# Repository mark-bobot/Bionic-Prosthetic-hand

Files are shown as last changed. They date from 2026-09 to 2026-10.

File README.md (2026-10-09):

# Bionic Prosthetic Hand

**One-wearer preparation:** [selected build and open acceptance gates](release/production/README.md). The latest files form an engineering bench kit; the device is not production-ready or approved for fitted use.

A three-servo adaptation of the e-NABLE Phoenix Hand v3, using a DFRobot SEN0240 dry-electrode EMG sensor and an Arduino Nano.

One servo drives the thumb, one drives the index and middle fingers, and one drives the ring and little fingers. When explicitly enabled for fixture commissioning, the controller commands closure on contraction and opening on relaxation; outputs ship disabled and mechanical operation remains untested. The original palm and finger shapes are retained.

**Before human testing:** [start with the unpowered printed-hand checks](docs/PRE-HUMAN-TEST.md). Current wiring and software preparation are included; physical verification and professional fitting remain outstanding.

## Latest routing variant — tendon drums underneath

The [bottom-drive candidate](cad/bottom_drive/README.md) inverts the three motors inside the enclosure and lowers the cord exits by 29.9–42.1 mm. The arm adapter and original hand are retained. A bolted upper motor carrier replaces reliance on hanging ties. Ideal pulling force is unchanged; reduced friction remains a bench-test question.

## Lower enclosure and rigid arm adapter

The [lower box and arm adapter](cad/cuff_box_compact/README.md) reduces enclosure height by 23.2%, retains one motor per pair of fingers, and adds a bolted arm carrier and palm receiver. It requires the shorter replacement-servo candidate; actual component fit and fitted use remain unverified.

## Earlier alternative — removable box above the original cuff

The [separate cuff-box design](cad/cuff_box/README.md) keeps the Phoenix hand and original gauntlet geometry unchanged. Three servos and upright Nano/EMG boards fit inside a strap-on enclosure; the battery stays external. This is a separate, minimally invasive packaging option. Its cuff view is an envelope, and wrist stabilisation and wearer fit remain unresolved.

## Historical alternative — components inside the forearm

[Historical 0.4.3 forearm guide](cad/forearm/README.md). A split, curved arm shell houses the motors, battery, electronics and tendon mechanism; the separate top box is removed. The original v3 placemat confirms the finger order; the previously inverted fingertips are now rolled correctly, with their pads toward the palm. The thumb now uses the original palm hinge, and the added side bracket is removed. The maximum forearm section is about **102 × 102 mm**. This version retains the low-profile replacement-servo candidate and revised power requirements.

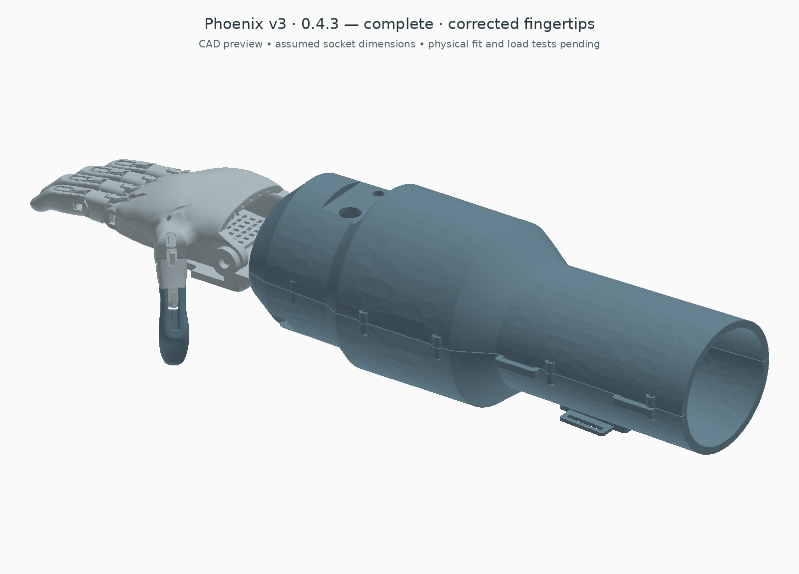
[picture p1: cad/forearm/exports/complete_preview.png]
Forearm-integrated design


[Hand layout close-up](cad/forearm/exports/hand_layout_preview.png) · [See the internal arrangement](cad/forearm/exports/open_preview.png) · [Electronics underneath](cad/forearm/exports/electronics_preview.png) · [Complete STEP](cad/forearm/exports/complete_forearm.step)

**Remaining limits:** the model assumes 160 mm from residual-limb end to wrist. Corrected fingertip poses pass the sampled collision checks, but recipient dimensions, continuous joint motion, tendon load and real hardware fit still need validation before this becomes a functional or fitted hand. The assembly reserves empty limb space rather than filling it with components.

## Adjustable hand sizing

The [sizing study](cad/sizing/README.md) adds an editable Phoenix scale percentage and independent arm-clearance dimensions. It preserves the original hand proportions and corrected fingertip orientation while keeping hardware full size. The illustrated 120% hand is a comparison, not a selected wearer size. The [new receiver and matching assembly](cad/sizing/ADAPTER.md) connect that hand to the housing with local screw-head clearances in the lower shell. An individually fitted socket remains outstanding.

## Build files

- [Arduino code and setup](firmware/README.md)
- [Wiring diagram](docs/WIRING.md)
- [Editable CAD, STEP and printable STL files](cad/README.md)
- [Right forearm attachment and movable EMG holder](cad/arm_interface/README.md) — unfitted concept
- [Bill of materials and cost allowances](BOM.md)
- [Candidate force and travel calculation](cad/slim/README.md#force-screen) · [Earlier generic-servo calculation](calculations/README.md)
- [Measuring tendon force](TENDON-TEST.md)
- [Checks performed](VALIDATION.md)
- [What remains](TODO.md)

## Earlier layouts

[The 0.3 smaller top-box candidate](cad/slim/README.md) and [0.2.1 external housing](cad/bionic/README.md) remain as history and sources for reused parts. Their assembly previews predate the finger assignment and thumb placement corrections. Use the 0.4.3 guide for current part selection; do not combine old shells or receivers with it.

[Simple averaging code](firmware/README.md) · [Current mechanical hardware](cad/forearm/README.md#selected-parts-and-hardware)

## Status

This is a newly reconstructed bench-prototype design. The Nano sketch compiles and the software control tests pass. The newly generated add-on parts pass solid/mesh checks; some original Phoenix STEP-to-STL conversions fail watertightness checks, so use the official source STLs. The hardware has not been assembled or tested: motor fit, tendon load, grip performance, electrical noise and thermal performance remain unverified.

The servos owned for this project are generic units advertised as 25 kg·cm with 180° travel. DS3225 dimensions and 5 V electrical specifications were historical references. The selected bottom-drive candidate instead uses FT5425BL references and its own power specification; neither identifies the owned motors. The initial code uses a small test movement; calibrate endpoints before expecting full finger closure.

The source project description mentions improved electrode contact, averaging sensor readings, tendon actuation and sharing a servo between two fingers. The files here implement a new version of that idea; they are not recovered original firmware or CAD, and do not establish earlier test results.

## Original design

Phoenix Hand v3 is credited by [e-NABLE](https://hub.e-nable.org/p/devices?p=e-NABLE+Phoenix+Hand+v3) to Jason Bryant, John Diamond, Scott Darrow, Andreas Bastian, Team Unlimbited, e-NABLE France and Jeremy Simon. It derives from Phoenix Hand v2 and Unlimbited Phoenix Hand, with labelled pins among the v3 changes.

The [original Thingiverse design](https://www.thingiverse.com/thing:4056253) is CC BY 4.0. The official STEP file is included unchanged; new carrier, spool, guide and equaliser parts are separate. The mechanical change is rerouting wrist-driven tendons to external servo actuation. No endorsement by the original designers is implied.

## Licences

Documentation and mechanical CAD: **CC BY 4.0**. Original firmware: **MIT**. Included OYMotion filter files: **BSD-2-Clause**, with their notices retained. Arduino's Servo library is an external **LGPL-2.1-or-later** dependency. See [LICENSE.md](LICENSE.md).

This is an educational bench prototype, not a validated fitted prosthesis.

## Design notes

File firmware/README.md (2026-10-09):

# Firmware

**10 October 2026: servo outputs are disabled by default.** `SERVO_OUTPUTS_ENABLED = false` is a commissioning lock, not a human-use approval mechanism. Read [pre-human-test preparation](../docs/PRE-HUMAN-TEST.md) and [current wiring](../docs/WIRING.md). No person connected during initial commissioning.

Open `ProstheticHand/ProstheticHand.ino` in Arduino IDE. Select **Arduino Nano / ATmega328P** and install Arduino's **Servo** library. The OYMotion EMG filter is included beside the sketch, so there is no separate EMG library to install. Some older Nano bootloaders require the IDE's Old Bootloader option.

## The simple averaging step

Open `ProstheticHand/ProstheticHand.ino`; keep its helper files in the same folder. The sketch reads A0, filters the signal, averages its activity and moves the three groups together. The averaging helper in `HandControl.h` is:

```cpp
sum -= history[index];                 // oldest sample out
history[index] = uint32_t(value * value);
sum += history[index];                 // newest sample in
index = (index + 1) % AVERAGE_SAMPLES;
level = sum / AVERAGE_SAMPLES;          // mean of 32 consecutive activity samples
```

`value` is the filtered EMG after the arithmetic-range clamp. Squaring before averaging measures activity; averaging the raw signal alone would drift around its DC bias and can hide contraction. `AVERAGE_SAMPLES = 32` gives a 32 ms window at the 1 kHz sampling rate. Change the three `OPEN_US`/`CLOSE_US` pairs only after calibrating the real mechanisms. Calibration, arming and the hold timeout remain in the helper so the main sketch stays short.

## What it does

The sensor connects to A0. The code samples at nominally 1 kHz, uses OYMotion's 50 Hz notch/high-pass/low-pass filters, squares the filtered signal using 32-bit arithmetic, and averages 32 consecutive samples. This follows the processing direction of [DFRobot's SEN0240 example](https://wiki.dfrobot.com/sen0240/docs/20737), with averaging and servo control added.

On reset, keep the muscle relaxed for five seconds. The first second lets the filter settle; the remaining four estimate the largest resting activity. The closing threshold is three times that resting peak plus 25, with a minimum of 100. These are initial tuning choices, not universal physiological thresholds. Activity must exceed the threshold for 80 ms before closing. It must fall below half the threshold to reopen. A grip command times out after three seconds and requires relaxation before another grip.

There is one EMG channel. It commands all three groups together; it cannot independently select a finger or grip pattern.

| Pin | Connection |
| --- | --- |
| A0 | SEN0240 A; add 1 MΩ to GND |
| D2 | Normally-open momentary hold-to-enable switch to GND, internal pull-up |
| D9 | Thumb servo signal |
| D10 | Index/middle servo signal |
| D11 | Ring/little servo signal |
| 5V | Clean regulated 5 V logic supply; not servo power |
| GND | Shared signal reference, with motor returns routed separately |

## First run

1. Program with electrodes removed, servo supply off and external logic supply disconnected from the Nano. Unplug USB before body-connected battery testing.
2. On the fixture, provide a resting test input and leave the enable switch open. Wait five seconds. The LED lights when calibration completes; rapid blinking indicates a latched fault. Calibration alone does not enable outputs.
3. For the first servo check, remove horns/tendons and confirm motor model and supply. Deliberately set `SERVO_OUTPUTS_ENABLED = true` and recompile for the fixture test. Release the switch **after calibration** for at least 50 ms, then hold it to enable. A switch held across startup/reset remains inhibited. Simulate rest, activity and rest; never use a person as the initial test input. Reattaching commands `OPEN_US`; it does not know the motor's physical position.
4. `OPEN_US = 1100` and `CLOSE_US = 1300` are deliberately small test movements, not full closure. Determine unloaded endpoints one servo at a time, then attach loose tendons and increase travel gradually. Never use nominal angle alone to establish the real range. Change the arrays separately if a servo must turn in the other direction.
5. Set `PLOT = true` only for diagnostic logging using an appropriately isolated arrangement, or with electrodes disconnected. Output columns are activity, threshold and close command. Do not connect a mains-connected computer while electrodes are worn.

A signal that stays above threshold prevents a new grip after rearming or timeout. Motor noise can trigger false contractions: test with motor power off and on before loaded tendons. Wearer calibration is a separate professionally reviewed stage. A lost or noisy electrode can still look plausible.

## Limits

The software does not measure tendon tension, grip force, temperature or actual finger position. The ADC rail check can catch some broken connections but cannot reliably detect electrode loss: a disconnected/noisy electrode can still look valid. The arm switch detaches servo signals; servo gearing may remain resistant to movement. It is not an emergency mechanical release. The main power switch and accessible tendon release remain necessary for bench work.

A sampling delay of at least 2 ms latches a fault. The loop schedule has not been measured on hardware; the compiled firmware is not a real-time validation result.

## Reproduce checks

```
arduino-cli core install arduino:avr
arduino-cli lib install Servo
arduino-cli compile --fqbn arduino:avr:nano:cpu=atmega328 firmware/ProstheticHand
c++ -std=c++11 tests/control_test.cpp -o /tmp/control_test
/tmp/control_test
```

Original control code: MIT. Included `EMGFilters.cpp` and `.h`: OYMotion BSD-2-Clause, with notices retained. Source linked by DFRobot: https://github.com/YeezB/EMG_Filter at commit `867fa1d30244b22f28a68787adfd5648066c4736`. Arduino Servo is an external LGPL-2.1-or-later dependency; no firmware binary is distributed here.

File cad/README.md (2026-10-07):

# Mechanical build

**Current direction:** [0.4.3 forearm-integrated Phoenix](forearm/README.md). Electronics and motors are inside the split arm shell. The former top-box and custom-hand studies are superseded.

The Phoenix v3 palm, fingers and joints are kept unchanged. The new parts form an internal forearm equipment bay, with a corrected finger assignment and thumb restored to the native palm hinge. Full source-joint flexion remains unaccepted. Tendons are rerouted from the original wrist-powered actuation to the servos. This is the current reconstruction; it is not evidence that the original project used this exact arrangement.

## Earlier smaller-part option

[Low-profile replacement-parts candidate](slim/README.md) reduces the housing to 50 mm high. Its complete assembly is `slim/exports/complete_slim_candidate.step`. It requires different servos and power wiring; do not mix the old electrical BOM with this candidate.

## Historical build selection

The historical 0.2.1 selection is recorded in [BUILD.md](../BUILD.md). It used the compact 60 mm housing, single-groove spools, Phoenix v3 source hand and external tendon cassette; its STEP is `bionic/exports/complete_right_bionic.step`. Use [the forearm guide](forearm/README.md) for current files and acceptance gates.

[Revision B](INTEGRATION.md) and the motor-only files below are historical designs. Their base, lid and double-groove spool must not be substituted into the current package.

## Original motor-only files

| File in `exports/` | Quantity | Purpose |
| --- | ---: | --- |
| `servo_carrier.stl` | 1 | Three standard-size servo pockets on a strap-mounted base |
| `two_groove_spool.stl` | 3 | 12 mm groove-floor radius drum; one per servo |
| `pair_equaliser.stl` | 2 | A small floating bar that divides one tendon pull between two fingers |
| `tendon_fairlead.stl` | 3 | Two-bore tie-on guide; PTFE tubing separates tendon from printed plastic |

STEP versions are included for editing. `carrier_assembly.step` includes rectangular reference servo envelopes; those are not printable motor parts. `build.py` is the parametric source, tested with CadQuery 2.8.0. Millimetres throughout. Run `python cad/build.py` to regenerate.

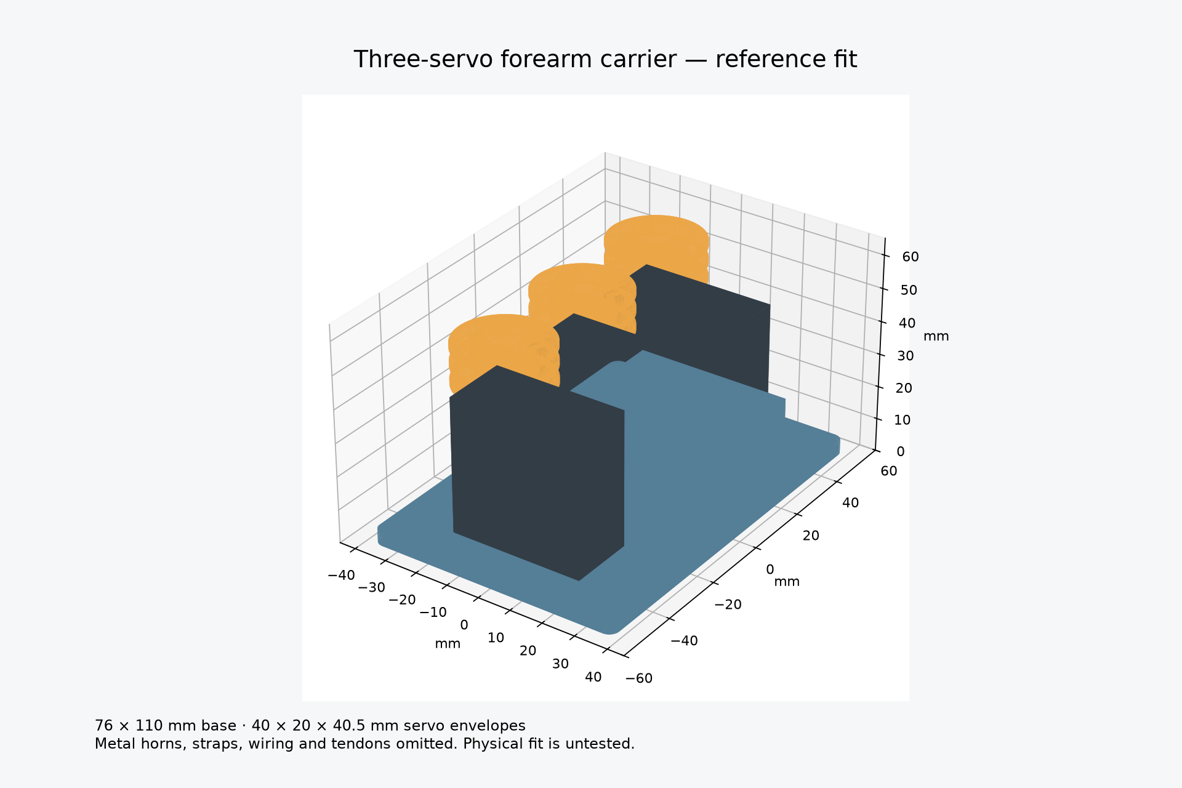
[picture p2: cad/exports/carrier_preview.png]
Carrier


## Carrier and servo retention

The base is 76 × 110 × 4 mm. Each pocket accepts a 40 × 20 mm reference body with 0.5 mm clearance per side. Retaining walls rise 11 mm above the base. There are cable exits and slots for a 4.8 mm tie around the rear of each motor, clear of the assumed output shaft position. Four outer slots take two 25 mm straps; a foam layer belongs between the plate and its support.

This is a test-fit fixture. The reference body dimensions are from DS3225 data; ear shape, lead exit, shaft offset and horn height are not established for the owned servos. The drawing uses a 10 mm shaft offset from the body centre and 3 mm horn clearance as layout assumptions. Check these before printing the full carrier. Servo ears must remain above the short walls and ties must clear the rotating horns. If the body is larger, edit `BODY_L`, `BODY_W` and clearance rather than forcing it into a pocket.

Use the carrier on a bench fixture first. Its width is 110 mm and its nominal assembled height is about 60 mm; this is not a compact palm enclosure or a fitted medical cuff. Final forearm attachment needs actual dimensions and a comfortable load-spreading cuff. It has no direct screw-hole attachment to a Phoenix part, so no Phoenix mounting-hole alignment is claimed.

## Horns and spools

Bolt each printed spool to a metal horn that fits the actual servo spline. Do not try to print a replacement spline. The spool has two 2.3 mm-wide mounting slots centred 8 mm either side of its axis and 6 mm central screwdriver access. Match a horn whose holes fit those slots; otherwise edit the slot positions. Reuse the correct manufacturer horn-retaining screw. Two M2 bolts and nuts per spool are a starting attachment specification; verify bolt length and clearance against the selected horn.

Each groove is 3.75 mm wide. Feed and knot the tendon through its radial anchor hole. Keep one layer of winding: effective radius is the 12 mm groove floor plus half the line diameter. For 0.6 mm line it is approximately 12.3 mm; use that in the torque/travel calculation. Verify the knot clears neighbouring parts and cannot pull through.

## Finger grouping

- D9: thumb; a single line from spool to thumb tendon.
- D10: index and middle; a line from one spool groove to the centre of an equaliser, with the finger tendons tied to its two outer holes.
- D11: ring and little; the same equaliser arrangement.

The unused second spool groove is a spare. Using an equaliser avoids forcing both paired fingers through identical displacement. The bar has 20 mm between outer holes and can accommodate some difference by tilting. Leave room for that motion and keep it away from the other lines. It is not unlimited compensation: if it flips or reaches a stop, stop and adjust the routing. The spool moves approximately the average of the two finger tendon displacements, and its input load is their sum in the nearly parallel arrangement. Measure the real coupling rather than assuming the direct two-groove model in the earlier sizing note.

Retain Phoenix return bands and joints. Disconnect the flexor lines from the original wrist-powered tensioner and route five finger tendons to these three groups. The carrier does not require cutting the original palm. Use the guide blocks at the carrier exit, with 2 mm OD / 1 mm ID PTFE liners and generous bends. Tie the guides to a fixture or cuff; do not leave them unsupported. No exact guide-to-palm path is claimed without hand scale and wrist geometry. Wrist motion can change tendon length, so keep the wrist at a fixed position for the first bench test.

## Printing and inspection

Start with PETG, 0.2 mm layers, four perimeters and approximately 40% infill as trial settings. Print carrier base down, spools axis vertical and equalisers flat. Horizontal cable/anchor bores may need careful clearing; inspect every guide for sharp edges. Print one spool and a pocket test before committing to the full set. These settings are not strength validation.

All four generated parts pass single-solid validity and watertight STL checks. The servo-envelope check finds no volume overlap with the carrier. These checks do not verify actual servo fit, tie retention, layer strength, horn screws, wear or load capacity.

## Original Phoenix file

`upstream/phoenix_v3.step` is the unchanged STEP download linked by the e-NABLE Phoenix v3 catalogue. It imports as 32 solids. SHA-256: `3d7086af7fd8a3b8f33ca87d8af6b10bdc7fc9038eb923bf920633acd7227620`.

Source: https://drive.google.com/file/d/1qt4fIh77aN9F0LTXMMZCiVgzgbxBcUQ3/view
Catalogue and attribution: https://hub.e-nable.org/p/devices?p=e-NABLE+Phoenix+Hand+v3

Phoenix v3 by Jason Bryant, John Diamond, Scott Darrow, Andreas Bastian, Team Unlimbited, e-NABLE France and Jeremy Simon; based on Phoenix v2 and Unlimbited Phoenix. Upstream geometry is CC BY 4.0. New mechanical parts and their parametric CAD source are also CC BY 4.0. No endorsement is implied. Use the official assembly and sizing instructions for the original hand; do not infer recipient fit from this STEP file's scale.

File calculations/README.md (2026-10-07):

# Historical generic-servo force and travel calculation

For the current FT5425BL candidate, see [candidate ratings](../cad/slim/README.md#force-screen). To enter real measurements, use the [actuator-end pull checker](MEASURED-PULL.md). The generic 5 V estimates below are retained as history.

Generated by `python3 calculations/tendon_forces.py`. These are screening calculations, not a measurement of the Phoenix hand.

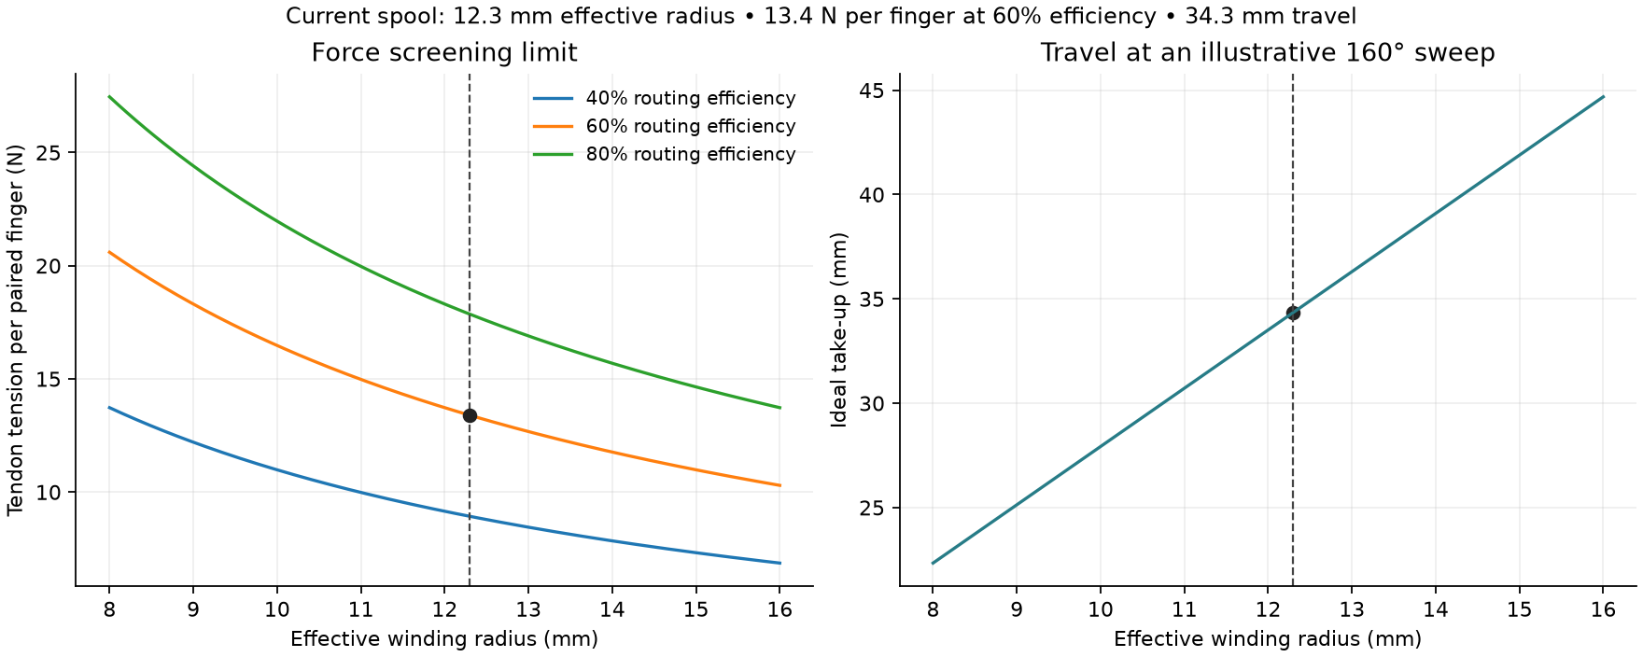
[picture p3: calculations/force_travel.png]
Force and travel trade-off


Optional plot: run `python calculations/plot_forces.py` with matplotlib installed.

## Inputs and equations

Reference stall torque at 5 V: 21 kgf·cm. Assumed working fraction: 40%; torque allowance: 0.824 N·m. Apply a separate 1.5 load margin. Neither allowance is a manufacturer continuous rating.

The new 6.75 mm-high single-groove spool retains its 12 mm groove-floor radius. With 0.6 mm line the effective radius is 12.3 mm. One line pulls a floating equaliser for each pair; one line pulls the thumb. Equal-arm, parallel-line geometry is assumed.

`required torque = margin × radius × (T1 + T2) / routing efficiency`
`equal finger tension limit = efficiency × working torque / (2 × margin × radius)`
`take-up = radius × angular travel in radians`

## Available finger-side tendon tension

| Routing efficiency | Paired fingers, each (N) | Single thumb (N) | Illustrative fingertip force per paired finger (N) |
| --- | ---: | ---: | ---: |
| 40% | 8.93 | 17.86 | 0.49 |
| 60% | 13.39 | 26.79 | 0.94 |
| 80% | 17.86 | 35.72 | 1.39 |

The fingertip column uses `(tendon tension − 4 N) × 5 mm / 50 mm`: an assumed equivalent return/friction tension, tendon moment arm and contact lever. These are not dimensions extracted from Phoenix CAD. A multi-joint finger needs pose-dependent tendon moment arms and contact geometry. Tendon tension is not grip force. The thumb column is tendon tension only.

## Torque required by an assumed load, 60% routing efficiency

| Finger-side tendon pull per finger (N) | Design torque (N·m) | Design torque (kgf·cm) | Within assumed allowance? |
| --- | ---: | ---: | --- |
| 5 | 0.307 | 3.14 | Yes |
| 10 | 0.615 | 6.27 | Yes |
| 15 | 0.922 | 9.41 | No |
| 20 | 1.230 | 12.54 | No |

Required pulls include return bands, finger-joint friction and desired contact load, but exclude routing friction already represented by efficiency. For unequal loads use their sum; a jammed finger can invalidate the equal-load assumption.

## Travel

| Usable sweep | Ideal line take-up |
| --- | ---: |
| 18° | 3.86 mm |
| 120° | 25.76 mm |
| 160° | 34.35 mm |
| 180° | 38.64 mm |

160° is an illustrative calibrated range, not the firmware command. The small initial firmware sweep is about 18° on the reference servo. For an ideal equaliser, input travel is the average of output travels; its tilt and mechanical stops must accommodate their difference. A 20/30 mm finger-travel pair needs 25 mm centre travel and 10 mm differential travel. An equaliser hitting a stop no longer shares force as assumed.

If measuring with a force gauge at the servo end through the complete routing, the total input-force screening limit is **44.65 N**. Compare `1.5 × measured input force × 0.0123 m` against 0.824 N·m; do not divide by routing efficiency again.

## What the numbers establish

At 60% routing efficiency the model supports about 13.4 N per paired finger. Two fingers requiring 10 N each are within the assumed allowance; two requiring 15 N each are outside it. Actual required closure force is unknown. Measure maximum force and travel with return bands installed, first unloaded and then on a bench contact fixture. Record breakaway peaks and the highest winding radius. Do not tighten live tendons on a wearer to establish these values.

Reducing spool height preserves the force/travel calculation; reducing radius would raise force but reduce travel. The new spool still requires real horn, screw-head, tendon-anchor and printed-strength checks. These force estimates do not validate the motor restraints, wrist cradle or socket.

[Manufacturer reference datasheet](https://dsservo.com/d_file/DS3225%20datasheet.pdf), checked 5 October 2026. The owned generic servo is not identified by this reference.

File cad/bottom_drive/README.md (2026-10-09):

# Bottom tendon drive

This variant turns the **three motors and their drums upside down inside the enclosure**. The arm adapter, palm receiver and original Phoenix hand stay in the same position. The cords leave near the bottom of the box, outside the arm shell; they do not run against the residual limb.

The change is worth testing because it lowers the tendon exits and the lever acting on the box mount. It does **not** increase the motor's torque or change the drum's mechanical advantage.

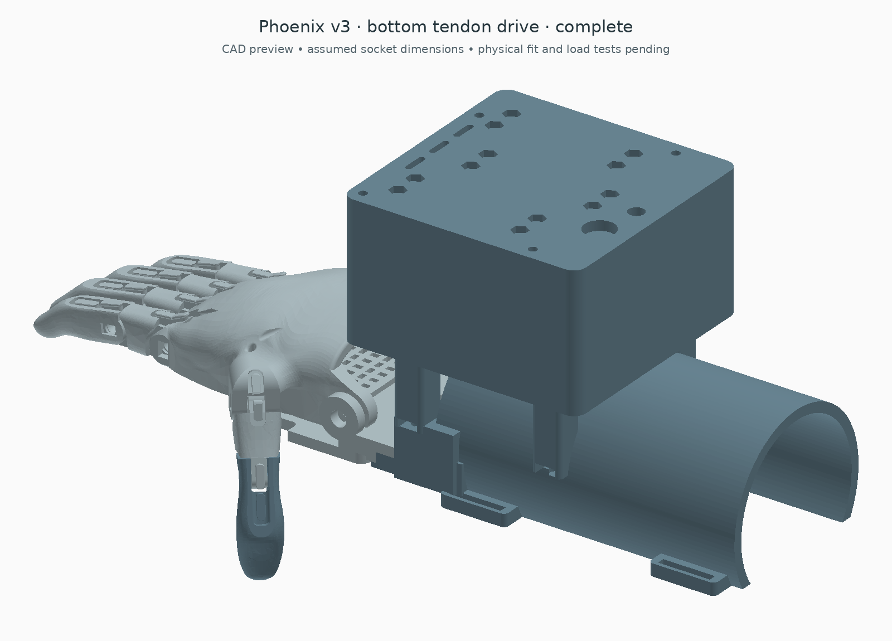
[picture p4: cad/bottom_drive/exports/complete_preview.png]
Complete reference


[Drums viewed from below](exports/drive_detail_preview.png) · [Open box](exports/open_preview.png) · [Complete STEP](exports/complete.step) · [Geometry checks](exports/checks.json) · [Before/after schematic](exports/routing_comparison.png) · [Calculated comparison](exports/routing_comparison.json)

## What changes

- Motors point down, with their drums protected inside the case.
- A 4 mm upper cover carries the motor locating seats and mounting pillars. Four M3 bolts per motor pass through the servo ears into captive nuts in the cover. Ties are not the primary hanging restraint.
- The drawing-based ear-hole pattern is 49.5 × 10 mm. Actual screws, horn and ear fit still require a measured servo.
- The five tendon exits move from 42.4 / 48.5 mm above the box floor to 12.5 / 6.4 mm. This lowers individual exits by 29.9–42.1 mm.
- The box remains 94 × 96 × 54.9 mm. External fastener projections and cable bends are not included in those body dimensions.
- The lower arm adapter and its four M4 mounting points stay unchanged.

The load path is drum → servo case → ear bolts → structural cover → cover screws → case → M4 arm mounts. The cover and its fasteners therefore need load testing as structural parts.

The mechanism still has **three servos**: thumb; index/middle; ring/little. Each paired motor winds two independent cords in separate grooves. It gives fixed coupled travel, not an adaptive differential.

## What this does to force

Effective drum radius remains 12.3 mm. At the same motor torque, the ideal pull is unchanged: for equal paired cords, each tension is approximately torque divided by twice the radius. Ideal 160° take-up remains 34.35 mm.

Lower exits can make the external route less steep. Less sliding contact and less total bend can reduce losses, but merely shortening a free, straight cord does not increase pulling force. The final external route through the Phoenix hand has not been measured or validated, so **no percentage reduction in required motor torque is claimed**.

A flexible-line friction model illustrates why bends matter: the tension ratio depends exponentially on friction coefficient times total contact angle. For example only, reducing total sliding contact from 90° to 45° would reduce the required driving tension by about 4–15% for assumed coefficients 0.05–0.20. Neither those coefficients nor those angles have been established for this hand. [Engineering Statics: flexible-belt friction](https://engineeringstatics.org/Chapter_09-flexible-belt-friction.html)

For the earlier illustrative 10 N per hand tendon / 60% efficiency / five parallel exit cords, the box pitch reaction about its seating plane drops from 3.74 to about 0.84 Nm. That is a geometric internal-load comparison, not a wearer-joint torque, structural rating or measured efficiency improvement. Tendon forces also react at the palm. Reproduce with comparison.py.

## Parts and assembly

Use this folder's box_base and box_lid together. The cover is now a structural motor carrier; the old plain cover cannot support this arrangement. Other print types remain rear_board_carrier, two_groove_drum (two copies), thumb_drum, arm_adapter and palm_receiver: seven types, eight pieces.

The smaller FT5425BL replacement-servo candidate, Nano, SEN0240 and external power arrangement are retained from the [lower-box guide](../cuff_box_compact/README.md). This still does not identify the generic servos already owned. The original motor data and dimension drawing are in the [manufacturer specification](https://www.feetechrc.com/Data/feetechrc/upload/file/20210810/6376418710101296552903409.pdf).

The paired drums have only 1.8 mm nominal bare-flange clearance above the 4 mm floor. The M2 drum fasteners must project no more than **1.2 mm below the drum**, leaving just 0.6 mm nominal clearance. This tight allowance needs a measured horn/fastener stack and printed clearance check; ordinary projecting cap heads or nuts are not automatically compatible. Do not assume the earlier drum hardware fits. [Swept head-clearance check](exports/drum_hardware_checks.json)

Add twelve M3 motor-ear through-bolts and twelve nuts. Select lengths against the actual ear, printed pillar and nut engagement; the CAD's motor-head allowances are 6 mm diameter × 3 mm, not a purchased-fastener fit certificate. Inspect the small carrier ligaments, print orientation and hanging-motor retention on a bench. Retain the four cover fasteners, box-to-arm fasteners, board fasteners, horns and drum attachments described in the previous guide.

Assemble motors and horns on the removable upper cartridge. Install drums from below while the cartridge is out of the box. Thread and adjust the cords with the mechanism unpowered. For service, unload/slacken the cords and disconnect power before lifting the cartridge; do not lift the cover against tight finger tendons. Lead slack and the service movement are not fully modelled.

Because the motors are inverted, **do not assume the previous closing direction or endpoint settings remain correct**. Calibrate each motor with its cords disconnected. Firmware now ships with outputs disabled and requires a post-calibration enable-switch release before arming. Its positions remain uncalibrated for real hardware. See [current wiring](../../docs/WIRING.md), [EMG mounting](../../docs/EMG-MOUNTING.md) and [fixed-groove measurements](../../calculations/BOTTOM-DRIVE-PULL.md). Keep cords in one layer and verify reliable reopening and a manual means of releasing tension.

## Acceptance boundary

The original generous full-height ear-envelope check is replaced here by the drawing-positioned ear shapes and holes because the new mounting pillars intentionally occupy space above those ears. Case, ear, drum, head and printed-part collisions are still checked.

The CAD checks cover the printed parts, reference components, mounting-ear/head allowances, straight internal cord segments, arm-space clearance and sampled hand poses. The view from below omits the housing deliberately to show the mechanism; the real drums remain enclosed.

Missing: measured external tendon routes, continuous moving-cord clearance, knots, horn fit, actual fastener insertion, service cable slack, motor duty/temperature, print strength and individual arm fit. The main reason to keep this variant is its lower routing and mounting lever; bench comparison must establish whether it actually pulls more efficiently.

Original hand geometry and attribution are retained. Mechanical CAD is CC BY 4.0. This is an unfitted bench prototype.

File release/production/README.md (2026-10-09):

# One-wearer build preparation

**Status: NOT READY FOR FITTED USE OR PRODUCTION.**

**10 October update:** the user has the original Phoenix v3 print only; no extension or wiring. Start with [pre-human-test preparation](../../docs/PRE-HUMAN-TEST.md). The kit now includes current wiring, EMG mounting notes, a fixed-groove measurement checker, blank bench record and output-disabled firmware. These changes do not close any physical acceptance gate.

Target: one wearer with a right missing hand; retain original Phoenix hand geometry, three-motor paired-finger drive, Nano and SEN0240. Selected mechanical candidate: cad/bottom_drive. No commercial distribution or clinical approval is asserted.

The candidate is a starting point for engineering and prosthetic fitting, not a prescribed socket. No wearer measurements, clinical fitting record, physical assembly, measured tendon load, validated manual release or durability evidence has been supplied.

## Selected build

Use only the seven print types listed by [the bottom-drive guide](../../cad/bottom_drive/README.md): base, structural motor cover, rear board carrier, two paired drums, one thumb drum, arm adapter and palm receiver. Eight pieces total. The original right Phoenix hand must be obtained at the selected scale from the credited official source; the repository's source STEP conversion is not a newly validated printable hand kit.

The generated manifest freezes the exact selected STL, STEP, firmware and report hashes. The package script rejects stale source/output hashes, failed CAD checks, inconsistent quantities and missing files. It does not manufacture evidence or approve fitted use.

    python release/production/package.py
    python release/production/package.py --require-production

The second command deliberately exits nonzero while the physical/fitting gates remain open. Do not use the historical release/package.py kit for this candidate.

## Purchased-part completion

| Item | Quantity | Current state / required closure |
| --- | ---: | --- |
| FT5425BL candidate servo | 3 | Verify exact revision, ear/shaft/horn dimensions and delivered samples |
| Metal horns and shaft screws | 3 sets | Exact horn SKU, hole pattern and engagement unselected |
| M2 drum fasteners | 6 | Measured projection must be ≤1.2 mm; nominal remaining floor gap only 0.6 mm |
| M3 motor ear bolts and nuts | 12 sets | Select actual length and retainers against printed carrier |
| M3 cover / board-carrier sets | 4 / 2 | Specify lengths, head style, torque and retention after sample fit |
| M4 box / palm-receiver sets | 4 / 2 | Verify stack, engagement, tool access and no exposed limb-side tips |
| Wrist axle, retainers, stops and palm strap | 1 set | Sizes and reliable anti-rotation restraint not physically accepted |
| Arm straps, liner, socket interface | Wearer-specific | Prosthetist selection; do not order by placeholder cylinder dimensions |
| Classic 5 V Nano | 1 | Verify board revision and installed connector envelope |
| SEN0240 kit | 1 | Measure supplied conditioner, electrode and connector/contact geometry |
| Separate 5 V logic regulator | 1 | Verify noise, current and dropout across selected supply range |
| Motor supply, fuse, disconnect, wiring, connectors | 1 system | Exact rated parts unselected; do not inherit older generic-servo power kit |
| Tendons, liners and return bands | 5 paths / hand set | Specify material, diameter, terminations, friction, wear and release method |

Prices and a final procurement total are intentionally unresolved. A partially specified BOM is not a purchase-ready production BOM.

## Fitting and verification sequence

1. A prosthetist establishes residual-limb condition, socket/liner geometry, suspension, usable muscle sites, functional goals and fitting limits. Record the prescribed hand scale, limb clearance and alignment. Do not derive acceptance from the existing 32 mm radius.
2. Identify and inspect the purchased components. Record serial/lot, dimensions, datasheet revision and photos. Fit a horn/drum and a mounting coupon before a complete print.
3. Establish the print process: material/batch, machine, orientation, layer/perimeter settings, supports and post-processing. Qualify that process with representative loaded parts; generic infill settings are not a strength certificate.
4. Assemble on a rigid fixture. Inspect every force-transmitting joint, fastener and tendon termination. Verify actual moving clearance throughout travel, including the tight underside drum heads, and both directions of cover removal.
5. Define required hand tasks and measure each full-route tendon force/displacement, breakaway force, paired-finger behaviour and return-band reopening. Set load and travel limits from the measured system; stall torque is not the allowable operating torque.
6. Complete and test an accessible mechanical release. Disabling servo signals or cutting power is not assumed to release a geared grip. Check loss of power, seized motor and jammed tendon on the fixture.
7. Validate the electrical system: motor/logic rails, wiring and protection coordination, peak current, sag, interference, temperature and disconnect operation. Use an appropriate isolated arrangement for body-connected measurements; do not connect a worn electrode to a mains-linked bench setup.
8. Calibrate inverted winding direction and endpoints unloaded. Test EMG rest/contraction, motion artefacts, electrode loss, false activation, disarm, timeout, timing and restart with motors operating. The existing single channel cannot independently command finger groups or guarantee electrode-loss detection.
9. Agree and document load, cycle-life, temperature, release-time and wear acceptance criteria before qualification. Run repeated cycles and representative faults on the bench; record failures and rerun affected tests after fixes. No arbitrary cycle count is presented as clinical acceptance.
10. Only after engineering and fitting review, proceed through supervised unpowered fitting and any professionally approved functional trials. Record comfort, pressure, skin response, suspension, electrode stability and follow-up/maintenance needs.

## Evidence record

For each gate in readiness.json, retain: exact source revision/profile, hardware lots, test method and equipment/calibration, pre-agreed acceptance criterion, observations/raw data, result, date and responsible reviewer. CAD reports and firmware tests alone cannot close physical or fitting gates. The manifest remains marked blocked regardless of package integrity.

## Regulatory scope

For a one-wearer device supplied in Great Britain, establish the applicable pathway with the responsible manufacturer and qualified professional. A customised CAD file alone does not establish custom-made status or compliance. MHRA describes specific requirements for custom-made devices, including the prescription basis and manufacturer obligations. This package makes no classification or conformity determination.

Sources checked 9 October 2026: [MHRA custom-made devices](https://www.gov.uk/government/publications/custom-made-medical-devices/custom-made-devices-in-great-britain), [prosthetic/orthotic device guidance](https://www.gov.uk/government/publications/medical-devices-legal-requirements-for-specific-medical-devices/medical-devices-legal-requirements-for-specific-medical-de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).

Original geometry, software and licence notices are retained. This preparation does not substantiate past physical tests or personal-statement claims.

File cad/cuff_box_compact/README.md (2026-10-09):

# Lower box and rigid arm adapter

This version makes the preceding cuff box smaller and adds a physical connection between the motor box, arm carrier and unchanged Phoenix palm. It is an **unfitted bench prototype**, not a finished socket.

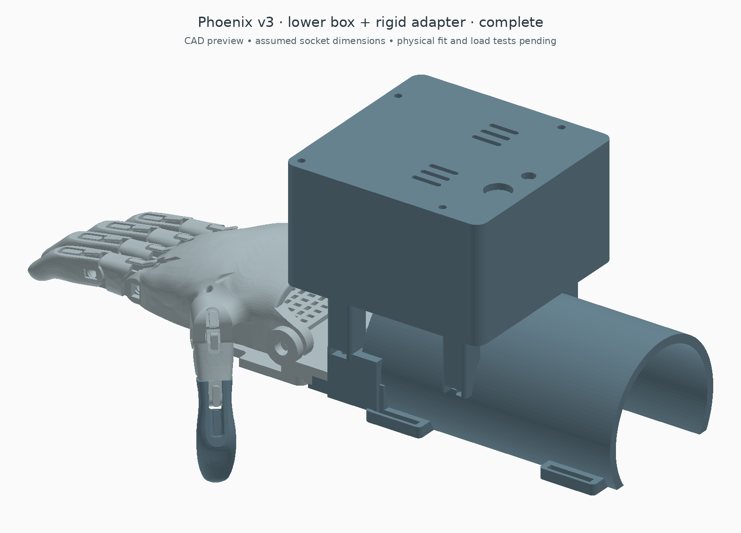
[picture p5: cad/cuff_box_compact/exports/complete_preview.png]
Complete design


[Inside the box](exports/open_preview.png) · [Complete STEP](exports/complete.step) · [Editable profile](profile.json) · [Geometry report](exports/checks.json)

## Size and motors

The box body is **94 × 96 × 54.9 mm**, down from 94 × 96 × 71.5 mm: **23.2% less height and bounding-box volume**. The old strap ears are removed, so maximum box width falls from 110 to 94 mm. The box underside moves down from global Z=50 to 44 mm. These comparisons apply to the enclosure, not the complete hand and new arm adapter.

There are **three motors total**:

| Motor | Fingers pulled | Drum |
| --- | --- | --- |
| D9 | Thumb | One groove |
| D10 | Index and middle | Two separate grooves |
| D11 | Ring and little | Two separate grooves |

Each paired motor pulls two individually adjusted cords. Both wind at the same radius and move together; this is not an adaptive differential. If one finger stops against an object, the other cannot automatically continue independently. Test this explicitly before grip trials.

The smaller case uses **FT5425BL replacement servos**, with the manufacturer's 40.6 × 20 × 30 mm case reference and 11.5 mm shaft offset. It does **not** establish that the unidentified motors already owned will fit. Ear width is conservatively reserved at 24 mm. Horn shape, cable exits and assembly clearances remain sample-dependent. [Manufacturer specification](https://www.feetechrc.com/Data/feetechrc/upload/file/20210810/6376418710101296552903409.pdf)

The Nano is turned sideways on the rear carrier. The SEN0240 signal board stays upright beside it. The battery remains external. Two-groove drums are 7.2 mm high; the thumb drum is 4.2 mm. Both retain the 12 mm groove-floor radius, with 1.2 mm flanges and 1.8 mm clear groove width. With 0.6 mm cord, nominal effective radius stays 12.3 mm and ideal 160° take-up stays 34.35 mm. Verify one-layer winding, knots and reopening in practice.

## Arm adapter and wrist

The new open carrier replaces the old cylindrical cuff illustration. It is an exported, printable part with:

- Four M4 attachment posts for the box, spaced 56 mm along the arm; countersunk seats keep the box floor flush under the motors.
- Side-entry captive-nut pockets, so mounting nuts can be inserted from outside.
- A distal bridge with two M4 attachment points for the palm receiver.
- A receiver using the existing Phoenix wrist bores, an under-palm support, a palm retention-strap path and two adjustable M4 stop/pad locations.
- Two arm-strap stations 85 mm apart, with 3 × 21 mm slots for nominal 20 mm webbing.
- An open underside between the straps for separate positioning of the dry electrode.

The hand, fingers and native thumb joint are unchanged. The new carrier replaces the original wrist-powered gauntlet. The wrist axle alone remains a hinge: the under-palm stop pads **and** palm retention strap must be fitted and tested to restrain rotation. Neither the palm strap, padding, stop heights nor axle retainers are validated by the CAD checks.

Default carrier inner radius is 32 mm, wall 4 mm, centre Z=8 mm. Its curved section runs Y=−160 to −38 mm; reserved clear limb volume ends at Y=−44 mm, before the distal bridge. A nominal 3 mm liner would leave 58 mm inner diameter. These are editable fixture dimensions, not anatomical measurements or a fitting range. The carrier does not provide a validated suspension system, tissue-pressure distribution or elbow clearance.

The electrode remains on an independent band against exposed skin, aligned with the relevant muscle direction; it is not buried behind the printed shell. DFRobot lists a 22 × 35 mm dry-electrode board. The existing carrier can be a fit-check starting point, but actual contact protrusion and comfort require measurement. [DFRobot sensor and placement information](https://wiki.dfrobot.com/sen0240/)

## Print and hardware selection

Use these files together; do not combine this box with the preceding strap-on base.

| Printed part | Quantity |
| --- | ---: |
| box_base | 1 |
| box_lid | 1 |
| rear_board_carrier | 1 |
| two_groove_drum | 2 |
| thumb_drum | 1 |
| arm_adapter | 1 |
| palm_receiver | 1 |

Seven print types, eight pieces. Each has matching STEP/STL exports at print Z=0. Assembly coordinates are recorded in the report. Review supports for horizontal passages and curved surfaces before printing.

Hardware: three matching metal servo horns/centre screws; six M2 horn-to-drum fasteners; six servo retaining ties; four M3 lid sets; two M3 board-carrier sets; four M4 countersunk box-to-adapter sets; two M4 receiver-to-adapter sets; two M4 stop screws with broad retained pads; matching wrist axle and retainers; two arm straps and one palm strap; padding; five retained short tendon liners. Verify all lengths against the print. Do not print a guessed servo spline. Slotted drum attachment is not proof of a particular horn fit.

Electronics: three FT5425BL candidate servos, classic Nano, SEN0240, separate regulated 5 V logic supply, suitably rated external motor supply, fuse, disconnect, distribution, wiring and grommets. Exact high-current components and prices remain unselected. The prior generic-servo 5 V power arrangement must not be reused unquestioningly.

At the manufacturer's evaluated 6 / 7.4 / 8.4 V points, three simultaneous stalls are 10.2 / 13.2 / 15 A. The existing candidate force screen gives 10.84 / 13.23 / 15.15 N per paired hand tendon with its explicit 60% efficiency and 1.5 margin assumptions. These are not continuous-duty or fingertip-force claims. [Calculation and power requirements](../slim/README.md#force-screen)

Firmware is unchanged: D9 thumb, D10 index/middle, D11 ring/little, A0 EMG, D2 arm. Calibrate endpoints with cords disconnected before loading. Bench-test release and provide a way to slacken the tendons manually; removing power may leave a geared motor holding its position.

## Mounting-load calculation

For an illustrative 10 N at each hand tendon and 60% routing efficiency, each paired motor requires 0.410 Nm and the thumb requires 0.205 Nm, before a separate design margin. The new box reaction about its seating plane is 3.74 Nm if all five exit cords run parallel to the forearm. The equivalent couple across its 56 mm mounting span is 66.7 N. This is a load case for the frame, not a bolt or strap rating. The old box calculation was 5.59 Nm about the cuff crown; lowering the exit height reduces this geometric lever by about 33%.

Tendon forces also react at the palm: these internal box moments are **not** the net torque applied to the wearer. The rigid bridge must carry both sides of that load path. [Reproducible load scenarios](exports/load_checks.json) are generated by the included load_check.py script.

## Verification and remaining work

The generator checks solids and meshes, internal reference-component/cord clearance, servo-ear envelopes, the adapter/receiver interface, reserved limb space, 13 sampled hand poses and exported assembly placement. These tests do not establish continuous tendon motion, print strength, measured hardware fit, mounting stiffness or safe worn use.

Six nominal mounting-screw shank/head allowances also clear the exported printed parts; see [mount checks](exports/mount_checks.json). This does not establish actual screw length, nut fit or tool access.

Build from the repository root with CadQuery 2.8, trimesh, numpy and matplotlib:

    python cad/cuff_box_compact/build_box.py

Identify and measure hardware, establish tendon loads, fit the wrist stops/retention, then test the assembly on a rigid fixture. A prosthetist or appropriate limb-fitting professional still needs to determine the residual-limb interface and suspension before powered wear.

Original Phoenix attribution and CC BY 4.0 notices remain in the repository. New mechanical work is CC BY 4.0.

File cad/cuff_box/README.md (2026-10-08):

# Separate box above the Phoenix v3 cuff

This is a new enclosure design, separate from the integrated forearm version. It puts three servos, the Nano and the EMG signal board in a removable box above the original gauntlet. The original hand, finger shapes, joints, return bands and printed gauntlet are retained. No new holes in those parts are proposed.

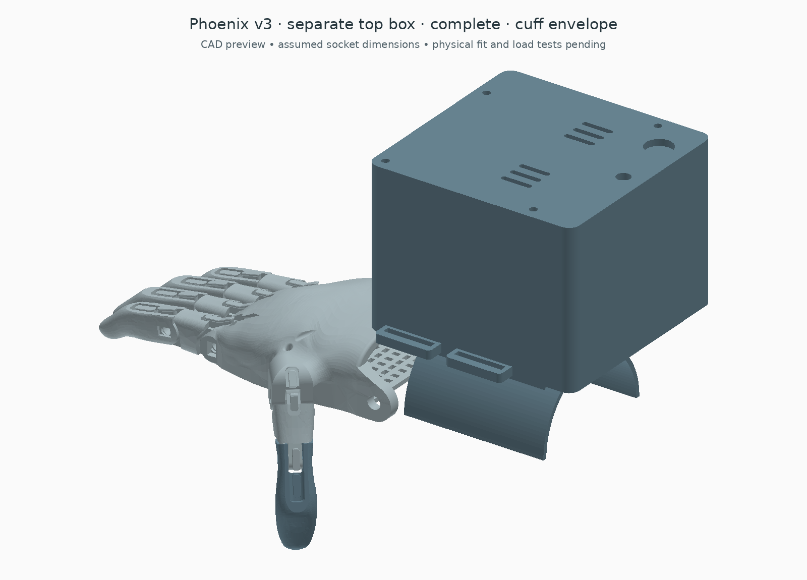
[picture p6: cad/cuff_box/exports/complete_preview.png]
Box mounted above a cuff envelope


[Mounting schematic](exports/mounting_schematic.png) · [Force worksheet](FORCES.md) · [Open view](exports/open_preview.png) · [Box by itself](exports/box_only_preview.png) · [Complete reference STEP](exports/complete.step) · [Box STEP](exports/box_only.step) · [Editable dimensions](profile.json) · [CAD checks](exports/checks.json)

The cuff in the assembled view is an **adjustable envelope**, not the exact original gauntlet after forming or a fitted socket. The hand and cuff are positioned for context; the original wrist-pin connection is not reconstructed in this view. The unchanged [flat source gauntlet](exports/original_flat_gauntlet_reference.step) is included separately. The official source is flat, and the [v3 assembly placemat](https://drive.google.com/file/d/1caT-qSH-01H-uLoA75pY2E4LHxce84tP/view) shows it heat-formed before assembly.

## What changes on the original hand

1. Keep the Phoenix palm, fingers, pins and return bands at their matching original scale.
2. Strap the padded enclosure feet above the formed gauntlet, using its existing strap-slot areas. Check the actual slots and formed contour before selecting the straps; no drilling is assumed.
3. Replace the wrist-driven tensioner function with the three servo drums. Reterminate the five finger cords at the drums while retaining the hand's existing tendon passages.
4. Route the dry electrode lead out of the box to its independently positioned forearm electrode. Only the signal-conditioning board goes inside the box.

The original tensioner mounting ridge can stay. The box floor is raised above the cuff crown to leave room for it. The source cuff is not cut or flattened to fit the enclosure.

**This is not yet a functioning wearable conversion.** Direct tendons react against the hand and cuff, so wrist stabilisation must be resolved before loading them. A free original wrist pivot can move instead of closing the fingers. For the previously specified missing-hand use, the original wrist-powered gauntlet also does not replace a fitted residual-limb socket and wrist connection. The [original v3 catalogue](https://hub.e-nable.org/s/e-nable-devices/wiki/208/e-nable-phoenix-hand-v3) describes its functional-wrist/palm requirements. Treat this as the removable actuator module for a supported bench assembly until those interfaces are settled.

## Layout

| Part | Position |
| --- | --- |
| Index/middle servo | Left, with a two-groove drum |
| Thumb servo | Centre, staggered rearward, with a one-groove drum |
| Ring/little servo | Right, with a two-groove drum |
| Nano | Upright at the rear; access USB with the lid removed |
| SEN0240 signal board | Upright beside the Nano |
| Separate logic regulator | Rear carrier, beside the sensor board |
| Power distribution allowance | Low down at the front |
| Main disconnect and arm switch | Lid, above the shorter rear boards |
| Battery and fuse | External; this keeps the enclosure short |

The box body is **94 × 96 × 71.5 mm** in the supplied example. Strap ears bring the overall width to 110 mm; the curved feet add height below the box floor. The motor footprint is 20 × 40.6 mm with a 40.5 mm body height. A larger 24 × 56 mm ear footprint is reserved above the low retaining walls.

These motor dimensions, shaft position and ear allowances are **assumptions for unidentified generic servos**, not confirmation that the user's motors fit. [profile.json](profile.json) exposes them. Measure the motors, horn, lead exit and connector before printing the final box. Changing a dimension reruns the packaging checks; the lid height follows the required motor/drum space and minimum electronics height.

The supplied cuff reference has a 32 mm outer radius and 3 mm padding allowance. The enclosure floor sits 10 mm above that nominal cuff crown. The two saddle rails follow the padded radius; the two strap stations are approximately Y=−63 and −30 mm relative to the hand's CAD wrist datum. Real thermoforming does not produce a perfect cylinder. This reference does not establish strap fit, pressure distribution, elbow clearance or retention under tendon load. The rear of the box overhangs the illustrated cuff by about 24 mm.

## Tendon drive

There are five independent cords. Each paired servo winds two cords in separate grooves at the same radius; the thumb servo winds one. This avoids a sliding equaliser cassette, but the two fingers in each pair have **fixed coupled take-up**. Adjusting the starting cord lengths can remove slack; it does not give independent adaptation when one finger contacts an object first. This version does not claim an adaptive grip.

The drum groove floor radius is 12 mm. With the illustrated 0.6 mm cord in one layer, the effective radius is 12.3 mm. An assumed 160° sweep gives **34.35 mm of ideal take-up**. Actual servo travel and required finger travel are unmeasured. Do not use a nominal 180° label as endpoint calibration.

For a paired motor, required spool torque is approximately `radius × (cord force 1 + cord force 2)`, before any additional transmission losses. For the thumb it is `radius × cord force`. Do not treat the advertised 25 kg·cm stall figure as usable continuous torque. A new measured-pull test is needed for this direct two-cord routing; the floating-equaliser test setup from the other design is not automatically equivalent.

The [force worksheet](FORCES.md) also calculates the mounting reaction. An illustrative 10 N per hand tendon with 60% routing efficiency produces about 5.59 Nm around the nominal cuff crown if all exit cords run parallel to the forearm. Two straps cannot simply be assumed adequate; this attachment needs a bench load test and a resolved wrist/socket interface.

Five front ports have 4.4 mm diameter × 4 mm deep liner seats, followed by 1.5 mm cord passages. The illustrated internal cords clear the case and other components in their straight routing. The external cords, knots, liner retention and moving wraps have not been validated. Keep winding to one layer and inspect return-band reopening, rubbing, uneven paired-finger loading and manual release before powered trials. Cutting servo power alone may not release a geared motor's grip.

## Printed parts

Use the files in this folder, not the older compact or integrated-forearm shells.

| Print | Quantity | Purpose |
| --- | ---: | --- |
| [box_base.stl](exports/box_base.stl) | 1 | Enclosure, curved feet, strap ears, motor seats and tendon ports |
| [box_lid.stl](exports/box_lid.stl) | 1 | Removable lid with switch holes and vents |
| [rear_board_carrier.stl](exports/rear_board_carrier.stl) | 1 | Upright Nano, EMG and regulator support |
| [two_groove_drum.stl](exports/two_groove_drum.stl) | 2 | Paired-finger drives |
| [thumb_drum.stl](exports/thumb_drum.stl) | 1 | Thumb drive |

That is five new print types, six printed pieces. Matching STEP files are alongside the STLs. Print files have minimum Z=0; assembly offsets are recorded in `checks.json`. The complete STEP contains reference components and is not a print-in-place model. Review slicing and supports, particularly the curved feet, horizontal passages and upright board carrier.

## Hardware and electrical notes

| Item | Quantity / requirement |
| --- | --- |
| Servos | 3 measured positional servos; owned model and voltage still unknown |
| Matching metal horns and centre screws | 3 sets; do not print a guessed servo spline |
| Horn-to-drum fasteners | 6 M2 sets fitting the 2.3 × 5 mm slots; verify hole spacing, engagement and underside clearance |
| Servo retaining ties | 6, up to 4.8 mm wide; two per motor through the base slots; keep buckles inside the box |
| Box straps | 2; box slots are 3 × 22 mm, original cuff slots must be checked; 15 mm webbing is a starting size allowance |
| Padding | Nominal 3 mm under the saddle rails; fitted contour and retention still need assessment |
| Lid fasteners | 4 M3 through-bolt/nut sets; length selected against the print, with screw tips kept clear of the cuff |
| Carrier fasteners | 2 M3 sets; check the 6.6 mm corner-to-corner nut pockets and engagement |
| Board ties/insulating pads | As needed for the three boards; slots avoid assuming PCB mounting-hole patterns |
| Short tendon liners | 5; seats allow 4 mm OD stock, but select ID and retention to suit the actual cord |
| Classic 5 V Nano, SEN0240, separate 5 V logic regulator | 1 each; component blocks are clearance references, not exact connector models |
| Main disconnect, arm switch, wiring and grommets | Measure actual bodies and ratings; the lid holes are 12.2 and 6.2 mm |
| External motor supply, fuse and suitable connector | Select together after identifying the servos and measuring current; no battery is inside this enclosure |

The existing firmware mapping remains D9=thumb, D10=index/middle, D11=ring/little, A0=EMG and D2=arm switch. See [firmware setup](../../firmware/README.md). Recalibrate all endpoints with tendons disconnected and then with the new routing. Servo power must come from its correctly rated supply, not the Nano's 5 V output. Motor voltage is deliberately unspecified here because the generic units remain unidentified.

The lid switch blocks and the horn-height gap are space allowances. Shaft/drum concentricity is checked, but this does not establish spline engagement, horn shape, bolt access, plug clearance or a complete electrical assembly. The slots and vents are not a water/sweat protection rating.

## Rebuild and validation

```sh
python cad/cuff_box/build_box.py
python cad/cuff_box/build_box.py --profile my_box_profile.json --output /tmp/my-cuff-box
```

The generator checks valid single solids and watertight positive-volume meshes for the five print types; static component/cord intersections; the larger servo-ear keep-outs; clearance from the nominal cuff volume; three finger/thumb poses against the new box; and placement matches after STEP export. It recovers shaft and drum axes from cylindrical faces. Source/profile/output hashes are saved in `exports/checks.json`.

These are discrete geometry checks, not proof of continuous tendon motion, safe attachment, heat/current performance, print strength or fitted use. The hand's source geometry and corrected fingertip poses come from the existing verified Phoenix assembly. No original geometry is drilled or cut.

Original Phoenix v3 geometry remains credited to its designers in the repository's [attribution and licence notes](../phoenix_v3/README.md#attribution-and-licence). This new mechanical design is CC BY 4.0. Earlier integrated-forearm and resized-receiver variants remain separate designs.

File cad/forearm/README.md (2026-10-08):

# Forearm-integrated Phoenix — 0.4.3 design candidate

This replaces the separate box mounted above the arm. Three servos, battery, Nano, EMG conditioner and tendon mechanism sit inside a split forearm shell. The original Phoenix v3 palm and finger shapes are retained. This is an unfitted bench-development design, not a working or wearable prosthesis.

Exterior

## Update in 0.4.3

The complete and close-up exports are now checked against the same eleven original hand solids, so stale fingertip placement cannot silently return. Preview and assembly hashes are checked during packaging. Thirteen simultaneous five-digit closure samples pass the documented collision threshold; [view a sampled flexion pose](exports/flexion_preview.png). These samples include the palm, other fingers, thumb, wrist support and both forearm halves. They do not simulate tendon forces or establish a continuous swept clearance.

The motor reference now follows the FT5425BL drawing: the shaft is offset 11.5 mm along the case, and each spool is centred on that axis. The shaft and slotted mounting ears are represented in CAD. No printed forearm dimensions changed. The actual motor, horn, screws and cables still require fitting. `servo_axis_checks.json` independently recovers the shaft and drum axes from the exported STEP and confirms that all three coincide. The nominal 0.1 mm shaft-top-to-spool-base gap does not establish a usable metal-horn connection.

## Hand correction

The layout is now checked against the **original Phoenix v3 right-hand placemat and STEP**, rather than inferred from the older v2 guide. The four distal parts remain **short index, long middle, long ring, short little**, with dorsal return-band features on the same side as the palm's return-band tabs.

The thumb now attaches at the **original palm hinge**. The extra side fork and its outrigger plate are removed. The hinge centre is recovered from the actual inner bearing faces, including the asymmetric shoulder: the clear gap is 6.5 mm. The displayed thumb is rotated 60° toward the palmar side about that original axis; this is a checked CAD pose, not a measured anatomical angle or a manufacturer-prescribed stop. Placing it flat in the palm plane caused interference. A small scallop in the added wrist support clears the sampled thumb motion, and its left strap slot moves inboard. No original palm or finger surfaces are cut.

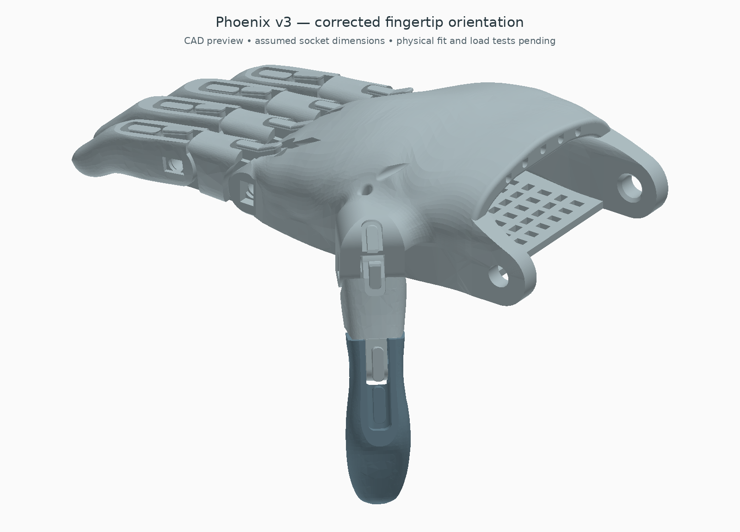
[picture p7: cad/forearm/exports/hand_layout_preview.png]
Original-joint hand layout


Sources: [official v3 catalogue](https://hub.e-nable.org/s/e-nable-devices/wiki/208/e-nable-phoenix-hand-v3), [right-hand placemat, both pages](https://drive.google.com/file/d/1caT-qSH-01H-uLoA75pY2E4LHxce84tP/view), and [original STEP](https://drive.google.com/file/d/1qt4fIh77aN9F0LTXMMZCiVgzgbxBcUQ3/view). The original Fusion archive was also retrieved and its embedded preview inspected; it was not opened as a native parametric assembly. See `source_review.json` for hashes and scope. The placemat is linked rather than redistributed.

**Fingertip correction in 0.4.2:** the upstream STEP is a printing layout, and all five distal parts are dorsal-side down relative to the proximal parts. They must roll 180° about their length before assembly. Earlier previews left them inverted; the visible tab at each PIP belonged to the proximal part, which concealed the error. The corrected fingertips put their own return-band tabs dorsally and their pads toward the palm. Original surfaces remain unchanged.

The displayed PIP/thumb-tip rest bend is 10°. With the corrected roll, a perfectly straight 0° pose overlaps the original extension-stop surfaces (about 2.66–3.41 mm³ for the four fingers); 10° clears them. This is a CAD rest setting, not a measured physical stop angle. `hand.py` records 40 adjacent-part checks through 60° MCP/PIP bends, all below the 0.001 mm³ reporting threshold (maximum approximately 0.000895 mm³). The previous larger 30–60° overlaps arose from the inverted fingertips; they are not evidence of a defect in the source design. The 45° MCP / 15° PIP assembly illustration also passes its checks. Pins, tendons, return bands, continuous motion and loaded closure still require validation.

## Inside the arm

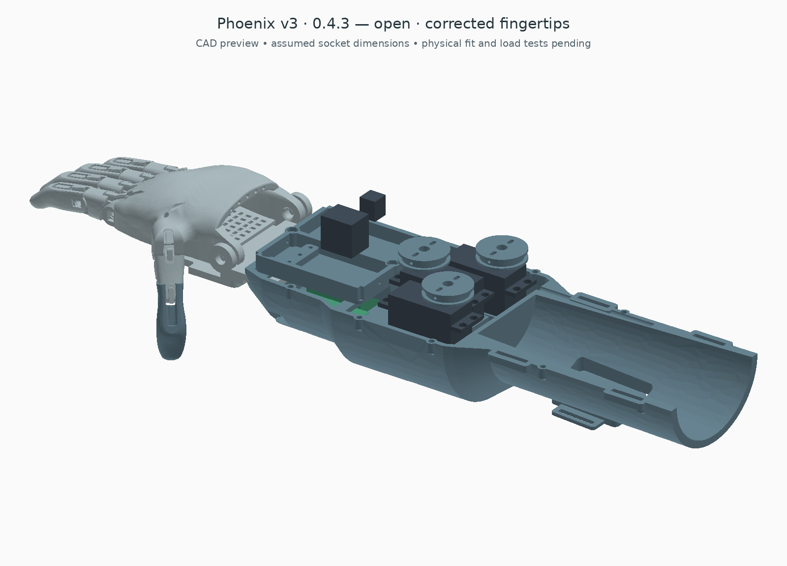
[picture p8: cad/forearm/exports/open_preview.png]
Upper shell and tendon cover removed


| Location | Parts and provision |
| --- | --- |
| Distal forearm, dorsal level | Three low-profile FT5425BL reference servos on an integral shelf, with low retaining walls and tie slots |
| Below motors | 70 × 32 × 22 mm battery allowance in a cradle; two 10 mm strap tunnels |
| Forward, below tendon mechanism | Removable Nano/EMG tray, separate 5 V regulator, fuse and distribution allowances |
| Forward, upper level | Two covered equaliser lanes and a separate lower thumb slider lane; five tendon exits |
| Upper shell | Recessed main disconnect and arm-switch positions |
| Socket underside | Window for an independently strapped SEN0240 electrode carrier, aligned with the placeholder socket taper |
| Socket side seam | Cable passage from the electrode area toward the equipment bay |

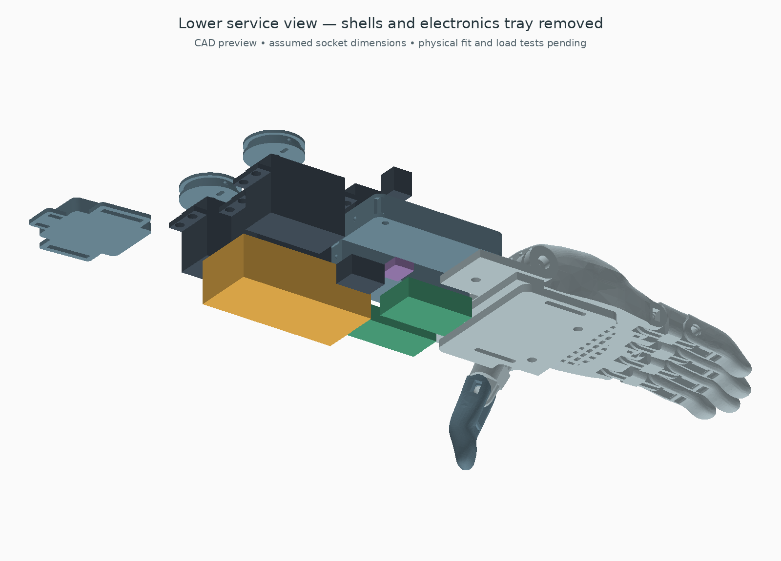
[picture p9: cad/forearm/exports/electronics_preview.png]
Electronics from underneath; both shells and tray removed


Green blocks are the Nano and EMG conditioner; gold is the battery; dark blocks are motors and electrical allowances. These envelopes do not include complete wiring, plugs, horns, straps or every fastener. Servo body and mounting-ear dimensions now follow the manufacturer drawing rather than the former ear allowance; rounded body details remain simplified. The electrode has an assumed 6 mm thickness; contact protrusion, liner clearance and muscle location still need measurement.

The shell is approximately **102 mm wide × 102 mm deep at its largest section**, including seam bosses. Its curved body is 279 mm long; the proximal opening to the hand's wrist datum is 295 mm. These dimensions describe the forearm, not the total spread hand. The three motors occupy different longitudinal positions so their spools do not overlap. The shell wraps this equipment instead of carrying a separate roof box.

Compared in the same CAD axes, maximum assembly depth falls from **145 to 110.4 mm**, about **24% less**. This uses more length: the full assembly's longitudinal bounds increase from about 317 to 432 mm because the equipment is beyond the limb end rather than stacked above it. It is a packaging trade-off, not a 24% volume reduction or proof of anatomical fit. `envelope_comparison.json` records both exported assemblies; regenerate with `python cad/forearm/compare.py`.

## Adjustable sizing

Use the [sizing study](../sizing/README.md) to change the original hand scale and inspect an independent limb/liner clearance envelope. It keeps hardware dimensions fixed, checks available arm length and makes anatomical/CAD landmark differences explicit. The sizing study itself does not rebuild the current shell or accept its receiver at a different hand scale. The [separate adapter candidate](../sizing/ADAPTER.md) supplies a new 120% receiver and a lower shell with two local screw-head clearance pockets. Use those replacement parts together.

## The space requirement that must be checked

The model reserves an empty socket from Y = −295 to −160 mm: **135 mm of socket length**, with nominal inner elliptical diameters of about 70 × 64 mm proximally and 54 × 50 mm distally. These are geometric placeholders, not measured anatomy or a liner specification.

It then assumes **160 mm from the residual-limb end to the wrist datum**. The equipment bay begins beyond the limb end, separated by a 3 mm bulkhead. No modelled equipment occupies the reserved limb volume. If the recipient has less distal space, this arrangement would make the arm too long: it must be repackaged around measured anatomy or use substantially different actuators. Do not shorten the socket or put components into occupied limb space to force a fit. Suspension, pressure distribution and alignment require individual fitting.

## Selected parts and hardware

Print-coordinate STEP/STL pairs are in `exports/`. Their minimum Z is zero; assembly positions are recorded in `checks.json`. `complete_forearm.step` is the assembly reference, not a print-in-place object.

| Added print | Quantity |
| --- | ---: |
| `forearm_lower`, with servo shelf and battery cradle | 1 |
| `forearm_upper`, with recessed controls | 1 |
| `electronics_tray` | 1 |
| `internal_tendon_base`, `internal_tendon_cover` | 1 each |
| `thumb_slider` | 1 |
| `palm_receiver`, with native-thumb clearance | 1 |
| `../compact/exports/single_groove_spool.stl` | 3 |
| `../exports/pair_equaliser.stl` | 2 |
| `../arm_interface/exports/emg_band_carrier.stl` | 1 |

Use the original right Phoenix hand/pins at the selected scale from the [official release](https://www.thingiverse.com/thing:4056253). Some source STEP-to-STL conversions failed earlier mesh checks, so the source hand's diagnostic meshes are not offered as accepted printable files. The source hand is included in the assembly STEP. Do not scale the whole motorised assembly: hardware dimensions would change.

Additional hardware allowance: ten M3 through-fastener sets for the shell seam; four for the electronics tray; four for the tendon base; two for its cover; two M4 sets at the forearm/receiver interface; and two M4 palm-support positions. Access and engagement lengths need to be selected against a print. The tendon cover captures two top-loaded M3 nuts in 6.6 mm corner-to-corner hex pockets, 2.4 mm deep. M3 × 6 mm cover screws are the starting allowance: check nut fit and engagement, and keep their tips above Z = 11 mm so they do not obstruct the lower thumb lane. These pockets provide metal threads; the printed clearance bores are not threads. The tendon-base motion check includes 6 mm diameter × 2 mm high screw-head allowances at X = ±30 mm, in 6.4 mm access pockets. Shell seam bosses have only about 1.3 mm radial wall around the bore and require a strength/print check.

Retain the original wrist axle/retainers, the original E thumb-knuckle pin, checked for fit, three matching metal servo horns and their retaining screws, six M2 horn/spool fasteners, servo ties, two socket straps, a separate electrode band, palm-retention strap, battery straps, insulating board pads, tendon, return bands and liner stock. Battery straps must fit the nominal 1 mm gap below the servo shelf (maximum 0.8 mm strap allowance). These counts specify CAD provisions; they do not establish load-rated attachment or a complete priced shopping kit.

## Electronics, pull and travel

The replacement-parts [electrical BOM and force model](../slim/README.md#replacement-bom-and-power-changes) apply: three FT5425BL candidates, classic 5 V Nano with low soldered connections, SEN0240 and separate 5 V logic regulator. A protected 2S rail feeds these particular servos directly. The owned generic servos are unidentified and are not approved for that rail.

At the retained 12.3 mm effective spool radius, the screening model gives about **10.8 / 13.2 / 15.1 N per paired tendon at 6.0 / 7.4 / 8.4 V**, using the lower of manufacturer rated torque and 40% stall torque, 60% assumed routing efficiency and a separate 1.5 margin. This is tendon pull, not fingertip force or continuous-duty approval. [Manufacturer data](https://www.feetechrc.com/Data/feetechrc/upload/file/20210810/6376418710101296552903409.pdf); generated values: `../slim/forces.json`.

The [measured-pull checker](../../calculations/MEASURED-PULL.md) accepts real actuator-end forces and travels without counting routing friction twice. Empty readings cannot produce a pass.

The new routing has not been measured. Longer bends and liners can reduce efficiency; repeat the [full-path tendon test](../../TENDON-TEST.md) before accepting these figures. Ideal take-up at 160° is 34.35 mm, within the 38 mm sampled slider range, but required hand closure travel remains unmeasured. The potential combined stall demand reaches 15 A at 8.4 V. Select the actual protected pack, disconnect, fuse, wire and connectors together; the earlier 10 A parts and 7.5 A fuse are not an accepted substitute. The CAD still contains reference volumes for those unselected components.

The existing [Nano firmware](../../firmware/README.md) is unchanged: smoothing, one EMG input and three linked servo commands. Calibrate each new servo with tendons disconnected. There is no active force/current feedback. The old generic-servo 5 V power diagram is historical; use the candidate topology in the linked electrical guide.

## Checks and rebuild

`checks.json`: seven valid single-solid added parts; watertight positive-volume STLs; no modelled static component/part overlaps above 0.001 mm³; no equipment intrusion into the reserved socket. `motion_checks.json`: both shell halves also clear that socket; 18 equaliser poses (three positions × three angles × two bars) and three thumb-slider positions clear the fixed geometry and sampled fastener heads. This is a set of discrete tests, not a continuous sweep. `layout_checks.json` records eight thumb samples: root angles −60°, −70°, −80°, −90°, each with 10° and 30° tip flexion. These clear the palm, thumb parts and revised support. Full opposition, pin fits, moving tendons and return bands remain unaccepted.

With CadQuery 2.8.0, trimesh, numpy, matplotlib and Pillow:

```sh
python cad/forearm/hand.py --check-motion
python cad/forearm/verify_layout.py
python cad/forearm/build.py
python cad/forearm/verify_motion.py
python cad/forearm/verify_closure.py
python cad/forearm/verify_servo_axes.py
python cad/forearm/previews.py
python cad/forearm/package.py
```

The hand diagnostic checks discrete poses with the corrected fingertip roll. It is not a continuous or loaded-motion test. Mechanical fit, cable bends, manual release, palm restraint, structural strength, EMG/motor-noise performance, battery protection and heat under load remain bench acceptance work. No hardware was assembled, powered or fitted for this revision.

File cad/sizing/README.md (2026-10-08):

# Adjustable Phoenix v3 sizing

The hand can change size while keeping the original v3 proportions. Edit `hand_scale_percent` in [profile.json](profile.json), then rebuild. The supplied **120% is an illustration**, not an adult size, a percentile or a size chosen for a wearer. The comparison uses 100%, 120% and 140% of the downloaded STEP geometry.

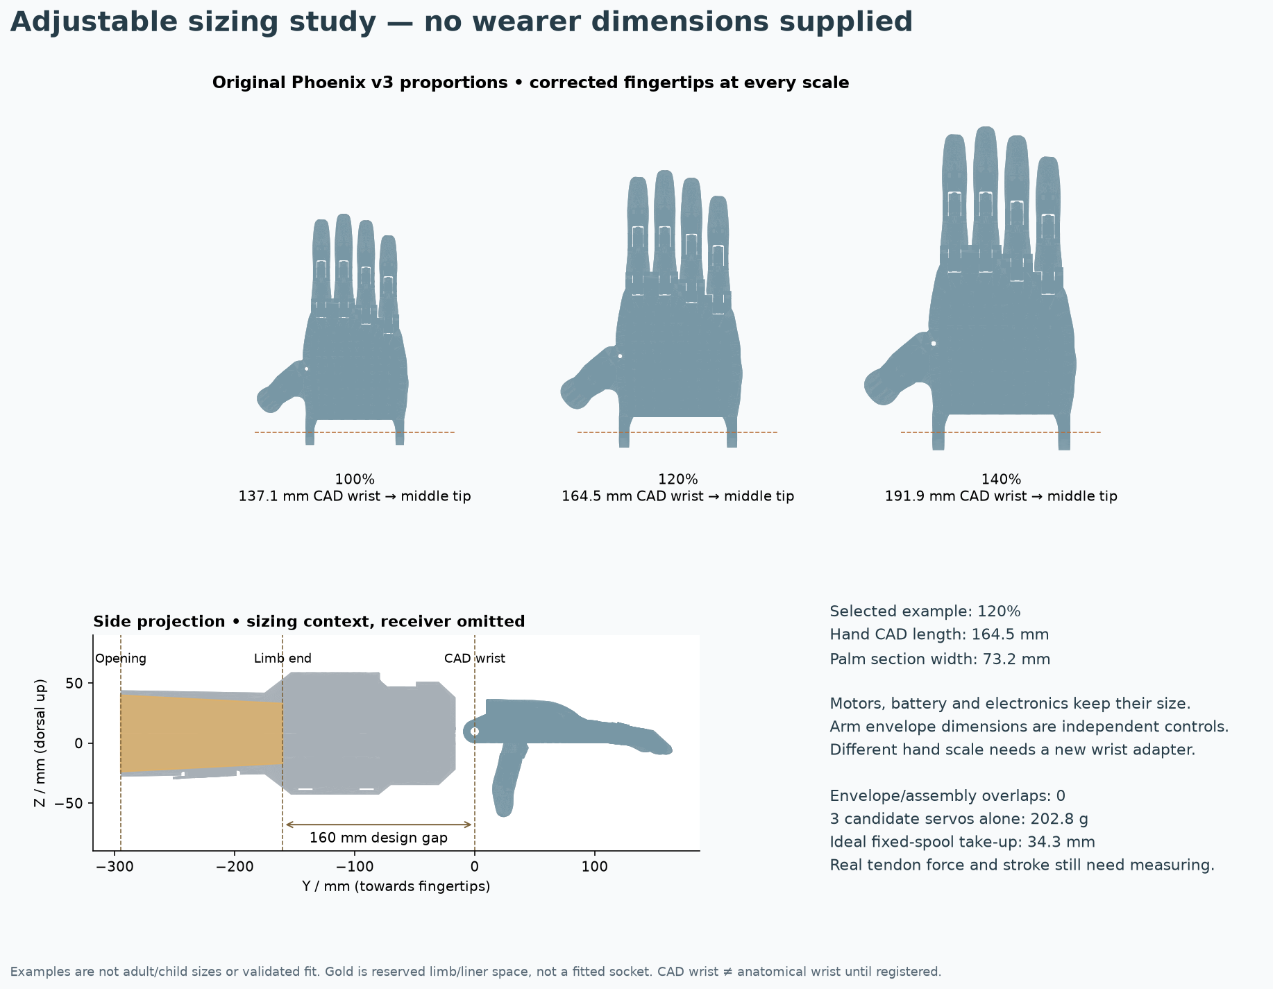
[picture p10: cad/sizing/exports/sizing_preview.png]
Sizing comparison and arm-space study


[Scaled hand STEP](exports/scaled_hand.step) · [Limb/liner clearance STEP](exports/limb_clearance_envelope.step) · [Dimension and clearance report](exports/sizing_report.json)

These are sizing studies alongside the [0.4.3 mechanical assembly](../forearm/README.md). The [separate adapter build](ADAPTER.md) connects the 120% example to the forearm using a new receiver and two local lower-shell screw-head clearances. Changing the sizing profile alone still does not rebuild the receiver or shell: run that adapter build and check its report. The side view on this page remains the independent sizing study and deliberately omits the receiver.

## What changes

| Control | Effect |
| --- | --- |
| `hand_scale_percent` | Uniformly scales the eleven original hand solids about the CAD wrist datum, including the corrected thumb and fingertips. Joint centres, finger lengths and palm shape remain in proportion. |
| `comparison_scales_percent` | Shows up to five sizes at a common drawing scale. These are design examples, not population size bands. |
| `opening_y_mm`, `distal_end_y_mm` | Set the ends of an independent clearance envelope reserved for the residual limb and its interface. They do not move the motors. |
| Proximal/distal width and depth | Change the two elliptical envelope sections independently. Width and depth are separate because circumference alone does not describe limb shape. |
| `axis_z_mm` | Moves the clearance envelope vertically for packaging studies. |
| `measurements` | Optional measured dimensions and registered landmarks. Leave unknown values as `null`. Missing data cannot produce a fit claim. |

The default envelope copies the existing CAD taper at the actual opening plane (about 69.77 × 63.80 mm), rather than rounding it outward to 70 × 64 mm. The extra decimal places come from CAD interpolation, not precise human measurements.

The motor, spool, battery, boards and switches keep their real CAD size. A different hand scale requires a new receiver and a check of the wrist axle, original printed pins, tendons and clearances. Scale the matching **original printed hand parts and pins** together using the official v3 files; do not scale bought screws, servo splines or the forearm assembly. This exporter supplies STEP reference geometry, not a newly validated set of printable source-hand STLs.

[e-NABLE's sizing guide](https://hub.e-nable.org/p/devices?p=e-NABLE+Device+Sizing) recommends virtual fitting and considers length and width separately. Its [v3 catalogue](https://hub.e-nable.org/s/e-nable-devices/wiki/208/e-nable-phoenix-hand-v3) describes a wrist-powered hand requiring a functional wrist and enough palm. We reuse that hand geometry; its original attachment is not a transradial socket.

## Landmarks before averages

In this CAD, Y=0 is the Phoenix mechanical wrist pin axis, +Y points toward the fingers and +Z is dorsal. That pin axis has not been registered to a person's anatomical wrist. The hand length reported here is the **Y projection from this CAD datum to the middle fingertip in the displayed rest pose**, not automatically a standard human hand-length measurement.

The palm-width value is the source palm's X extent in a narrow section at Y=60 mm, scaled with the hand. It excludes the misleading overall spread-hand bounding box. It is a reproducible CAD comparison station, not a recognised anthropometric landmark. Only enter `cad_palm_width_target_mm` after aligning an opposite-hand trace or scan to the model and choosing the corresponding station.

If a wearer is available later, register the opposite wrist and hand to the CAD, and record the signed offset `cad_wrist_distal_to_anatomical_wrist_mm`. Positive means the CAD joint is farther toward the fingertips. The checker then compares:

```
available distal space = elbow-to-opposite-wrist + wrist offset - elbow-to-residual-tip
hand length from anatomical wrist = scaled CAD length + wrist offset
```

Length-only and width-only scale suggestions stay separate. A single uniform scale may not match both. Do not stretch only one axis of the original joints to hide a mismatch. Virtual fitting, a different hand geometry or a deliberate redesign would be needed.

## Arm length is the main packaging constraint

The present motor/electronics layout needs **160 mm from the limb end to its CAD wrist datum**. The socket opening is another 135 mm proximally. These are design assumptions, not human averages. An 80 mm desired gap does not become feasible by changing `distal_end_y_mm`: the motors remain where they are and the envelope intersection check identifies any occupied space.

The report checks the adjustable envelope against all solids in the existing complete assembly, and the resized hand against the fixed assembly with the original receiver removed. An empty collision list means only that the tested geometry does not overlap. It does not establish room for a liner, wires, tissue movement or a good attachment. The envelope is a two-section geometric reserve, not a skin model, pressure map, custom socket or printable load-bearing part.

A fitted interface needs its own shape, trim lines, suspension and elbow-motion assessment. The historical [Atlas of Limb Prosthetics, chapter 8B](https://www.oandplibrary.org/alp/chap08-02.asp) discusses how these depend on residual anatomy and how test sockets can establish suspension and electrode sites. It is a 1992 reference, used here for those principles rather than a current fitting prescription. A prosthetist needs to assess the actual interface before wear.

## Human factors to carry into the fitted version

| Area | Design requirement and evidence still needed |
| --- | --- |
| Length and alignment | Match the registered opposite arm/hand where appropriate; assess reach and hand orientation. Repackage if the available distal space is too short. |
| Elbow and forearm movement | Check the proximal edge through the wearer's available elbow flexion and forearm rotation. The current opening position does not establish clearance. |
| Skin and attachment | Use a fitted, removable interface. Check pressure-sensitive areas, suspension, slip and edge contact. CAD ellipses and straps do not establish comfortable retention. |
| EMG | Place the dry electrode over a usable, signal-tested muscle site with stable skin contact. Do not choose the site just because it is the thickest or fattiest part of the arm. The present lower window is only an access provision; relocate it if the assessed site differs. |
| Donning and release | Demonstrate one-handed fastening, reachable power disconnect and an accessible tendon-release method. Power off alone may not release a geared servo's grip. |
| Heat and service | Keep battery/electronics separated from the interface; verify temperature, sweat exposure, wiring strain relief and access for removal. |
| Bulk and balance | Review the actual forearm section and measured mass, not just the outside silhouette. Avoid making the hand longer to hide the same equipment. |

The [DFRobot SEN0240 documentation](https://wiki.dfrobot.com/sen0240) identifies the dry-electrode sensor and its signal conditioning. It does not establish a fitted electrode location on a particular residual limb. The existing independently strapped carrier must be checked during signal testing rather than tightened to compensate for poor placement.

## Scaling affects travel and weight

The fixed 12.3 mm spool radius and assumed 160° sweep give 34.35 mm of ideal take-up. With the existing 3 mm slack allowance, the remaining ideal budget is 31.35 mm. At 120% hand scale, a first-order similarity estimate limits the **100% hand-only closure stroke to 26.12 mm**; at 140% it is 22.39 mm. Actual closure travel is still unknown. This estimate scales only the hand's stroke, not the fixed upstream routing, and does not model return-band changes or friction. Use the [measured-pull test](../../calculations/MEASURED-PULL.md) after resizing and rerouting.

The three candidate FT5425BL servos alone weigh **202.8 ± 3 g**, using the manufacturer's 67.6 ± 1 g specification. This excludes battery, plastics, fasteners and every other part. The checker calculates their approximate gravity moment about the elbow only when the elbow/wrist registration is supplied, using case centres as mass-centre estimates and a horizontal forearm. It does not invent an overall device mass or a comfortable load threshold. [Manufacturer specification](https://www.feetechrc.com/Data/feetechrc/upload/file/20210810/6376418710101296552903409.pdf), page 4.

## Rebuild and checks

Using the same CadQuery environment as the forearm:

```sh
python cad/sizing/build.py
python cad/sizing/build.py --profile my_profile.json --output /tmp/my-sizing-study
python tests/anthropometry_test.py
```

The build checks eleven valid source-derived hand solids, STEP round-trip bounds, volume scaling and the two sets of geometric intersections described above. Output hashes and source/profile hashes are recorded in `exports/sizing_report.json`. The source STEP is unchanged. Tests exercise missing data, landmark-offset signs, independent length/width suggestions, fixed equipment-space requirements and insufficient tendon stroke. Existing 0.4.3 motion results apply to that assembly, not automatically to a resized hand and a future new receiver.

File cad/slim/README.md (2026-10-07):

# Smaller-part housing candidate

**Historical layout:** [0.4.0 forearm integration](../forearm/README.md) is the current candidate. It corrects the index/ring distal-part assignment and open thumb placement shown in older assembly previews. Only reuse files explicitly selected by that guide.

This is an optional replacement-parts design, developed after prototype 0.2.1. It keeps the Phoenix hand, thumb placement, right forearm shell, EMG holder, spool radius and three-servo arrangement. **It requires different servos and power wiring; do not fit the existing unidentified servos or use the old servo power diagram unchanged.**

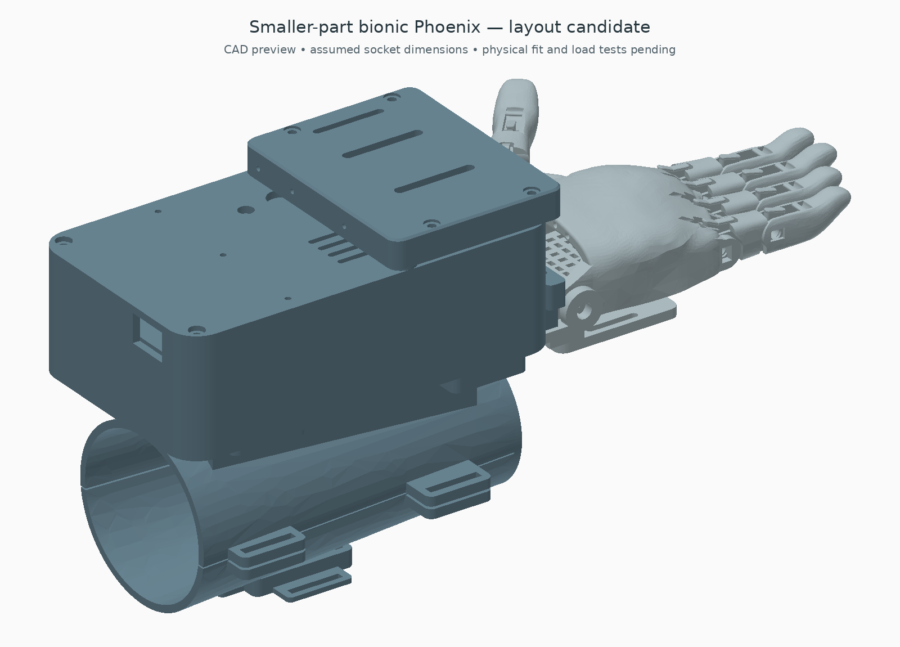
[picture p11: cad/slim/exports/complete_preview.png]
Smaller-part CAD


## What becomes slimmer

The main housing changes from **94 × 160 × 60 mm to 94 × 160 × 50 mm**: 10 mm, or 16.7%, less maximum height. Housing plus cassette changes from 73 to 63 mm above the housing underside: 13.7% less height. Width and length are retained so the socket, receiver and mounting centres stay compatible. These percentages describe the actuator pack, not the entire hand/socket volume.

- Three **FEETECH FT5425BL** low-profile positional servos replace the generic DS3225-size reference bodies.
- The classic 5 V **Arduino Nano is retained**, using soldered, strain-relieved leads instead of tall plug-in headers. Its 8 mm installed-height allowance must be measured, including USB connector, insulation and lead exits.
- The **SEN0240 and its electrode remain unchanged**.
- The old large servo regulator is omitted in this candidate. Servos use a protected 2S battery rail; the separate 5 V logic regulator remains. This saves a component but requires a revised high-current supply assessment.
- The complete tendon cassette moves down 10 mm. Equaliser stroke remains 38 mm; the wrist guide stays in place, so flexible liner lengths and bends must be re-established.

Servo case reference: 40.6 × 20 × 30 mm; positional travel 180° ±5° with 500–2500 µs commands and a 20 ms period. The manufacturer's drawing/actual sample must establish the final ear, shaft and horn fit. The historical slim CAD reserves 24 × 55 × 4 mm ears and 5 mm above the case before the printed spool. Current forearm 0.4.3 uses the drawing-based reference in `../forearm/servo_reference.py`, including the 11.5 mm shaft offset. These are allowances, not manufacturer drawing dimensions. [FEETECH specification, pp. 3–7](https://www.feetechrc.com/Data/feetechrc/upload/file/20210810/6376418710101296552903409.pdf).

## Force screen

Using the unchanged 12.3 mm effective spool radius, 60% assumed routing efficiency and 1.5 load margin, torque allowance is the smaller of 40% stall torque and the manufacturer's rated torque:

| Supply at servo | Torque allowance (kgf·cm) | Paired tendon pull, each | Thumb tendon pull | Three simultaneous stalls |
| --- | ---: | ---: | ---: | ---: |
| 6.0 V | 6.8 | 10.84 N | 21.69 N | 10.2 A |
| 7.4 V | 8.3 | 13.23 N | 26.47 N | 13.2 A |
| 8.4 V | 9.5 | 15.15 N | 30.30 N | 15.0 A |

Generated values are in `forces.json`; run `python cad/slim/forces.py`. Ideal 160° take-up remains 34.35 mm. Actual firmware starts with its small setup sweep. Compared with the earlier 13.4 N-per-finger screen, this candidate is similar at nominal 7.4 V but weaker at 6 V. Neither calculation establishes actual grip performance. Measure full-path tendon force and voltage sag before accepting the substitution.

A manufacturer rated-torque figure does not prove enclosed continuous duty. The previous 40% allowance was also an assumption. Heating and duty cycle still need measurement.

## Replacement BOM and power changes

| Item | Quantity | Candidate requirement |
| --- | ---: | --- |
| FT5425BL positional servo | 3 | Confirm exact revision, dimensions and metal-horn fit before ordering; no verified price quoted |
| Classic Nano | 1 retained | Low soldered connections, 8 mm installed-height allowance |
| SEN0240 kit | 1 retained | Same board/electrode; do not substitute a 3.3 V controller without checking analogue compatibility |
| Protected 2S battery | 1 | Existing 70 × 32 × 22 mm space is still an assumption; select and measure an actual pack, protection and connector |
| Logic regulator | 1 retained | 5 V D24V5F5; confirm dropout and EMG noise at lowest pack voltage |
| Servo regulator | 0 | Direct protected 2S supply for this candidate only |
| Main disconnect, fuse, connectors and distribution | 1 set | Re-select and verify for the new current path; old 10 A switch/pack and 7.5 A fuse are not accepted by this design |
| Nano lead insulation/strain relief | 1 set | Allow access for service; no exposed powered pads against shell |
| Servo horns and mounting hardware | 3 sets | Match actual 25T/5.9 mm output and printed spool slots; verify axial fastening |

At full battery voltage the datasheet permits a combined 15 A stall demand. Size the complete path for the intended current limit, conductor ratings and protection coordination; a battery's advertised C-rating alone is insufficient. The CAD reserves the old fuse/distribution/switch volumes, **not a verified 15 A parts set**. Real parts may force a housing adjustment. Do not simply increase the old fuse. No new battery/runtime/cost claim is made.

Power topology for bench development:

```mermaid
flowchart LR
  B[Protected 2S pack] --> F[Matched fuse and main disconnect]
  F --> S[Servo distribution: three HV servos]
  F --> R[Separate 5 V logic regulator]
  R --> N[Nano and SEN0240]
  N -->|D9 / D10 / D11 signals| S
  E[Dry electrode] --> N
```

Join signal and power grounds at the distribution reference; route motor returns away from EMG leads. The generic-servo 5 V supply diagram in the main build guide applies to 0.2.1, not this optional candidate. Initial tests should use an appropriate current-limited bench supply. Existing averaging/control code is retained; calibrate new endpoints with tendons disconnected. No additional battery monitoring or active force/current feedback is implemented.

## CAD selection

Print candidate `compact_base.stl`, `compact_tray.stl`, and `feedthrough_lid.stl` from this folder. Retain the three original single-groove spools and the 0.2.1 cassette, slider, equalisers, guide, receiver and shell files. Do not print `compact_lid.stl` for final assembly: it is the intermediate lid before liner entries. `complete_slim_candidate.step` records the lowered placement. All exported individual parts have their print-coordinate Z origin at zero; use the complete STEP for assembly positions.

The change moves the two front cover screw seats down 10 mm and the two rear seats down 7 mm; remeasure screw lengths. Cassette-cover fasteners and internal clearances are unchanged. Top switches now mount directly to the 3 mm cover instead of a recessed well. The Nano USB opening remains accessible in the layout; actual plug insertion and wire bends are not swept-clearance tested.

Rebuild with CadQuery 2.8.0, trimesh, numpy, matplotlib and Pillow:

```sh
python cad/slim/build_pack.py
python cad/slim/integrate.py
python cad/slim/forces.py
```

`checks.json` covers envelope/fixture intersections and generated pack solids. `integration_checks.json` covers the full static assembly. The cassette's internal sampled poses are inherited unchanged by rigid translation; this does not establish continuous articulation or flexible-line clearance. The socket remains an unfitted placeholder, and the candidate is not ready for powered wear.

## Alternatives screened

A much narrower KST X15-1208 has a 35.5 × 15 × 32.5 mm case, but its documented default travel is only 100°. At the existing spool radius that gives about 21.5 mm take-up. Changing spool size to recover travel would reduce pull, so it was not selected as a simple substitution. [KST manufacturer specifications](https://kstservos.com/products/x15-1208-cyclic-coreless-hv-digital-servo-motor).

The AGFRC A62BHL is shorter again at 26.5 mm, but its 17 kgf·cm stall rating at 6 V gives a lower assumed working-torque ceiling than the previous reference. It could be revisited after measured tendon loads establish the required margin. [AGFRC specifications](https://www.agfrc.com/index.php?id=2439).

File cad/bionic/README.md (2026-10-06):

# Right bionic Phoenix integration — prototype 0.2.1

**Historical layout:** [0.4.0 forearm integration](../forearm/README.md) is the current candidate. It corrects the index/ring distal-part assignment and open thumb placement shown in older assembly previews. Only reuse files explicitly selected by that guide.

This is the current integrated CAD for a right residual forearm with no hand. It combines the Phoenix palm and fingers, a fixed palm receiver with a connected thumb fork, a two-part forearm shell, component housing, and a removable tendon-drive cassette. Limb dimensions are placeholders; a fitted socket, suspension and load acceptance require individual assessment.

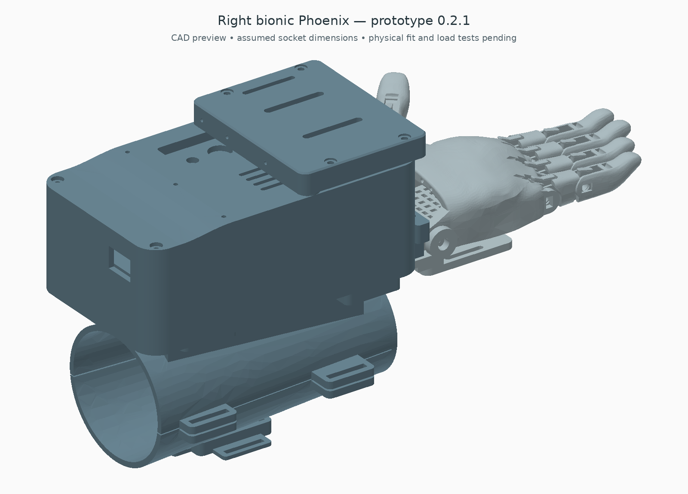
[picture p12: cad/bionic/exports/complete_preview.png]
Complete CAD


## Small exterior refinement — 0.2.1

The cassette now has continuous rounded walls matching its floor and lid, with 5 mm outer and 2 mm inner corner radii. A 0.8 mm chamfer softens the top lid edge. Four 6.2 mm diameter, 1 mm-deep screw-head seats reduce head protrusion while leaving 2 mm of cover below each seat; these are shallow recesses, not flush-head guarantees. The thumb-support plate has 5 mm rounded corners.

Housing size, cassette height, mounting centres, tendon ports, slider travel, source hand and component placements are retained. The new corners do not establish better strength or lower routing friction. No firmware changes are needed for this revision.

## Hand and attachment

The original Phoenix right palm and all finger solids retain their source shape and scale. No hole is drilled in the source palm. The new receiver uses the original wrist bores for an axle and supports the palm from below. Two M4 adjustment positions and a separate 20 mm palm-retention strap restrain rotation; fit and clamp load must be established on a bench. This is an added restraint arrangement, not a certified wrist lock.

The thumb is connected to a new fork on the receiver. Its source proximal and distal shapes remain intact; the root moves 18 mm outward and 6 mm upward. The fork points the thumb forward toward the fingers on a 50-degree in-plane axis. The new fork has 4.6 mm bores and 7.6 mm between its cheeks. Use a measured shoulder axle/bolt with washers and axial retention; a nominal 4 mm shoulder is a starting reference, with its play checked against the original 4.6 mm thumb bore. Do not tighten the cheeks onto the moving thumb. Root-body relief is cut in the new fork at sampled 0/15/30/45-degree positions. This establishes sampled root clearance, not full thumb articulation or grasp performance. Original pin E is not automatically compatible with the new fork.

The dorsal forearm shell closes at its distal end and accepts a removable ventral door. Separate releasable webbing joins their external strap stations. The door has a rounded 28 × 45 mm electrode access opening; the electrode itself is strapped independently to skin over a selected muscle belly. The signal board stays in the housing. The shell opening and movable holder allow access, but actual probe thickness/contact protrusion and skin pressure remain unverified.

Current lumen: 140 mm long, tapering from 54 × 50 mm distal to 70 × 64 mm proximal. These are fixture dimensions, not a prescription for the recipient. The liner, limb-end clearance, elbow clearance and anti-slip suspension must be designed around measured anatomy. This design does not require a functional wrist to power the fingers; its motor-driven actuation replaces that original Phoenix function. A prosthetist should fit the limb interface before powered wear.

## Component housing and drive cassette

Retain the compact base and tray. Use this folder's `housing_lid_with_feedthroughs` instead of the older compact lid. It provides three 2.4 mm liner-entry holes and restores the full cover thickness at the two cassette bearing seats. The Nano, SEN0240 signal board, reference battery, two regulators, fuse, switches and wiring spaces retain the compact layout. Battery, switch, servo-ear and added connector envelopes still need physical measurement.

The cassette bolts over the forward housing using its existing two front fastener positions. It adds space for two equalisers and one thumb-line slider; its lid is removable for access to knots and lines. Four 4.2 mm × 4 mm insert pockets receive selected M3 inserts; verify the insert's actual outer size and the printed boss before installing. The two cassette feet are 12 mm diameter to spread the mounting load on the cover.

The housing alone remains 94 × 160 × 60 mm. The cassette reaches assembly Z=77 mm, compared with the housing roof at Z=64 mm. The added drive space increases the package height. Flexible tubing/knots and fittings can extend farther; measure them before deciding the final outline.

The 7 mm internal floor-to-cover height leaves 1 mm below and 2 mm above the 4 mm bars and prevents a full 90-degree roll of their 8 mm-wide cross-section. Keep knots within the available top clearance; verify this with actual line.

The bars have 20 mm between finger-output holes. Their centre travel is 38 mm, sampled at three positions with ±30° tilt and the neutral pose. At ±30° an ideal bar accommodates about 10 mm difference between output travel. If one finger needs more difference, the bar hits its constraint and the assumed sharing no longer applies. The thumb has a separate guided line slider. This is a passive one-channel grasp: all groups move together from the single EMG control signal.

### Tendon connection map

Directions below use assembly coordinates: +Y points toward the fingers; left/right mean the pictured right-hand device, not a recipient fit prescription.

| Servo signal / physical position | Spool line | Cassette input | Cassette output |
| --- | --- | --- | --- |
| D9 / motor at X=-28 mm | Thumb | X=-37 mm rear port → thumb slider rear hole | Slider front hole → X=-37 front port → wrist comb → existing thumb route |
| D10 / motor at X=0 | Index/middle | X=-16 rear port → equaliser centre | Two outer holes → X=-26/-6 front ports → wrist comb → original two finger paths |
| D11 / motor at X=+28 mm | Ring/little | X=+16 rear port → equaliser centre | Two outer holes → X=+6/+26 front ports → wrist comb → original two finger paths |

One groove per servo. Keep a single winding layer and use 2 mm OD / 1 mm ID PTFE where appropriate. Three entry holes in the housing lid take the motor-side liners; route to the cassette's rear input ports with generous external bends. Five cassette output ports feed the wrist guide comb. The guide comb is mounted to the receiver with two M3 fasteners; its five 2.2 mm seats support the outgoing liners. Finish these paths into the **existing Phoenix tendon passages** following its assembly instructions. No rigid tube should bridge a moving finger joint.

Cord lengths, liner cut lengths, bend radii, plug clearance and knots must be set on a bench with the real hand and hardware. Flexible cords/tubes and their slack loops are not represented as validated swept geometry in the STEP. The ports and guide seats are real CAD features; the connection map defines the required installation. Use the cassette's removable cover to reach each input tie and release tendon tension manually after removing motor power; this is not a demonstrated emergency-release mechanism.

## Print list

| File | Quantity |
| --- | ---: |
| `socket_dorsal.stl` | 1 |
| `socket_ventral_door.stl` | 1 |
| `fixed_palm_receiver.stl` | 1 |
| `tendon_cassette_base.stl` | 1 |
| `tendon_cassette_cover.stl` | 1 |
| `thumb_line_slider.stl` | 1 |
| `wrist_guide_comb.stl` | 1 |
| `housing_lid_with_feedthroughs.stl` | 1 |
| `../compact/exports/compact_base.stl` | 1 |
| `../compact/exports/compact_tray.stl` | 1 |
| `../compact/exports/single_groove_spool.stl` | 3 |
| `../exports/pair_equaliser.stl` | 2 |
| `../arm_interface/exports/emg_band_carrier.stl` | 1 |

For the original right hand use the [official Phoenix v3 print files](https://www.thingiverse.com/thing:4056253) and the selected recipient scale. Some trial source STEP-to-STL conversions were not watertight and remain withheld. Source STEP bodies are included for editing/provenance. Regenerate new mounting geometry after choosing the scale; do not scale the servo, board or fastener features indiscriminately.

The new exports have minimum Z at zero; that is not a verified print orientation. Review the receiver fork, socket curves, ports and curved cover for support access and layer direction. Fit-test one bearing, spool/horn, insert seat and electrode holder before full printing. Material choice, skin-contact surfaces, cleaning, strap closures and liner are part of the fitting stage.

## Added hardware

| Item | Quantity | Fit/selection requirement |
| --- | ---: | --- |
| Retained wrist axle | 1 | Approximately 6 mm nominal; span the new 74 mm cradle width, with suitable end retention; check actual bores |
| Axle collars/end retainers | 2 | Outside the cradle cheeks; verify plain axle support and service access |
| Thumb shoulder axle/bolt, spacers, washers and locknut | 1 set | New 4.6 mm fork bores and original thumb bore; approximately 4 mm shoulder reference, adequate bearing length and checked play |
| M4 receiver-to-housing bolts, washers/nuts | 2 sets | Existing 36 mm transverse pitch; select length from actual floor/receiver stack |
| M4 adjustable lower stops with locknuts and soft pads | 2 sets | Seat on the printed palm; adjust without distortion; pads/load not validated |
| 20 mm palm-retention webbing with releasable closure | 1 | Around printed palm/receiver only; keep return bands, tendons and thumb clear |
| M3 front housing/cassette screws | 2 sets | Longer replacement for two original front cover screws; measure stack and nut engagement |
| M3 rear housing screws | 2 sets | Current rear cover stack; inspect head seats |
| M3 cassette-cover screws | 4 | 6.2 mm diameter × 1 mm-deep head recess, 2 mm remaining seat; measure actual head and insert/cover stack; ends must not reach moving lines |
| M3 heat-set inserts | 4 | CAD pockets 4.2 mm diameter × 4 mm; exact insert and boss fit verified first |
| M3 wrist-comb screws/nuts/washers | 2 sets | Select for actual comb/receiver stack and nut access |
| 20 mm shell-retention webbing with releasable closures | 2 | Trial shell stations; individual suspension still requires design |
| 20 mm independent soft EMG band and back retainer | 1 set | Contacts exposed, no rigid pressure screw |
| PTFE and braided line | Measured lengths | Three inputs, five outputs; cut after routing and stroke testing |

Retain the electronic/power BOM, three metal horns and M2 spool fixings, battery restraint, insulating board pads and tray screws. These additions are not included in the older revision B price total. Exact purchase choices depend on measured hardware and fit.

## Firmware

Open `firmware/ProstheticHand/ProstheticHand.ino` with its adjacent files. It reads A0, filters the EMG, squares it and takes a 32-sample moving mean. Relaxed calibration chooses a starting threshold; contraction commands all three servo groups, relaxation opens them. Arming and the hold timeout remain. See [simple averaging explanation and setup](../../firmware/README.md).

The small initial pulse sweep is deliberately a setup movement. Full-hand endpoints must be calibrated to this mechanism; there is no measured tendon-force feedback. Nano compilation and host control/filter tests are software evidence, not functional hand tests.

## Checks, forces and statement requirements

`checks.json` records valid single-solid/watertight new parts, static assembly collisions, 18 equaliser poses and sampled thumb-root clearance. These checks exclude full continuous articulation, flexible-line swept paths, fastener insertion, structural strength, thermal behaviour and patient fit.

The 12.3 mm effective spool radius is unchanged. At the reference 5 V torque and stated screening assumptions, available pull is about 13.4 N per paired-finger tendon, 26.8 N for the thumb, and 34.3 mm take-up at an illustrative 160°. The 38 mm cassette travel allows geometric room for that take-up; actual slack/stretch and safe end positions must be measured. Tendon tension is not fingertip force. New routing can add friction: use the [40/60/80% sensitivity calculations](../../calculations/README.md) and [force test](../../TENDON-TEST.md).

The current personal-statement v4 text was reread locally: Phoenix adaptation, compact packaging, forearm dry-electrode contact, averaging in Arduino, tendon actuation and paired fingers are the design requirements used here. New reconstruction files do not substantiate historical measurements or performance claims. No private statement is published.

## Reproduce

```sh
python cad/build.py
python cad/compact/build.py
python cad/phoenix_v3/build.py
python cad/arm_interface/build.py
python cad/bionic/build.py
```

Use CadQuery 2.8.0, trimesh, numpy, matplotlib and Pillow. `python cad/bionic/render.py` regenerates the depth-buffered preview directly from the complete STEP without rebuilding geometry. Preview colours are illustrative. The full source STEP hash is verified by the Phoenix build; original source attribution and CC BY 4.0 terms remain in that folder and the root licence. New work is AI-assisted prototype CAD.

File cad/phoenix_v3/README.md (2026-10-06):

# Current design: motorised e-NABLE Phoenix Hand v3

**Historical layout:** [0.4.0 forearm integration](../forearm/README.md) is the current candidate. It corrects the index/ring distal-part assignment and open thumb placement shown in older assembly previews. Only reuse files explicitly selected by that guide.

This is the requested Phoenix-based version. The palm, finger sections, tendon passages and original joint geometry come from the **official e-NABLE Phoenix Hand v3 STEP file**. The custom hand introduced in the previous study is superseded. The compact three-servo housing remains as the electronics/actuator module.

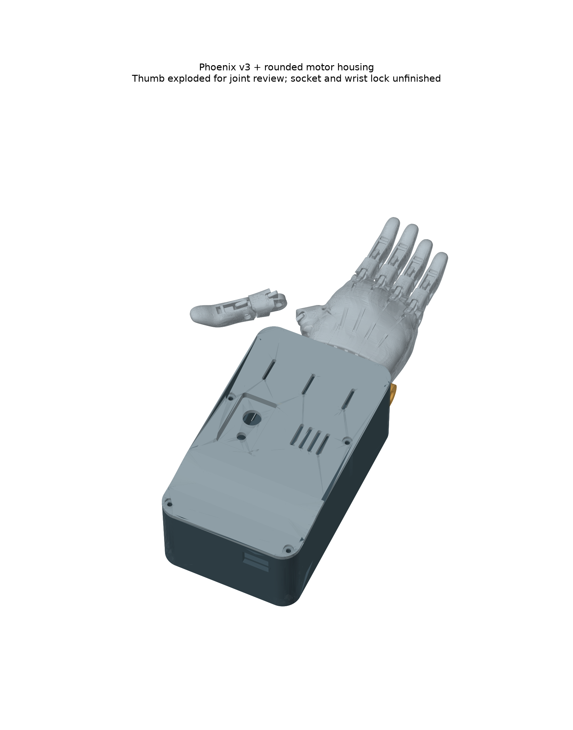
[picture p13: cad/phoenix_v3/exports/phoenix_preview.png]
Phoenix reference assembly


## What is retained and what changes

| Retained from Phoenix v3 | Added for motorisation |
| --- | --- |
| Original left and right palms | Compact three-servo housing, electronics tray and lid |
| Original five proximal and five distal sections | Three single-groove servo spools and two paired-finger equalisers |
| Original finger joints, pin geometry and tendon passages | A trial wrist cradle using the existing palm pivot bores |
| Original return-element approach | Arduino Nano, SEN0240 signal board, power electronics and battery |

No holes have been drilled in the source palm and no original finger shapes have been replaced. The exported source parts retain their original dimensions and coordinates. The reference assembly translates/rotates those bodies into a hand pose; it is not a print-in-place assembly. The thumb is shown exploded, 22 mm laterally and 12 mm upward, because its oblique joint orientation has not yet been verified. This display offset is not a proposed mechanical connection.

The intended actuation remains one servo for the thumb, one for index/middle and one for ring/little. The wrist-powered tensioner is not the intended motorised tendon drive. Original tensioner parts and arm guard are included for traceability, not as a requirement to print every source part.

## Wrist cradle and enclosure

`phoenix_wrist_cradle` is new geometry. Its coaxial 6.4 mm clearance holes reference the original palm's nominal 6 mm wrist bores. It bolts to the compact housing using two M4 clearance holes on a 36 mm transverse pitch. The housing is raised 4 mm onto the cradle's rear plate in the assembly.

The cradle is a **pivot-alignment prototype**, not a finished wrist connector. It still requires a retained axle, neutral-position lock/stops, strength checks and adaptation to the selected hand scale. The pivot must not remain free under loaded tendons. Do not substitute the original short wrist pins without checking their engagement in the wider cradle. The complete motorised wrist load path is not validated.

The rounded enclosure retains a 94 × 160 mm footprint and 60 mm maximum height at the motors. The roof falls smoothly to 57 mm at the rear, with 12 mm outer corner radii, recessed switch controls and recessed cover screws. The 6.75 mm-high spools retain the 12 mm groove-floor radius while removing the unused second groove. Print these from `cad/compact/exports`, not the older two-groove part. The lid requires slicer support/orientation review. See [component dimensions and assumptions](../compact/README.md). Its reference motor ears, battery and switches are not measurements of the user's parts. Board, connector and cable fit still require physical checks.
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

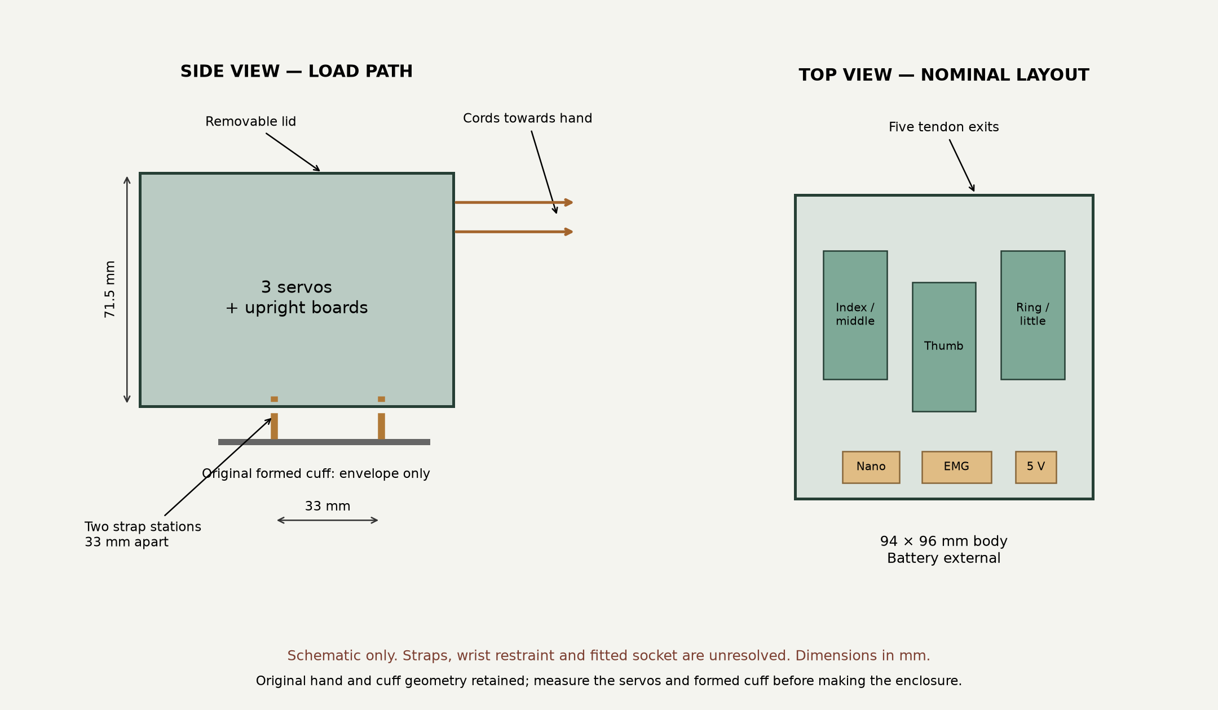
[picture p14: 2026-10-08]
cad/cuff_box/exports/mounting_schematic.png

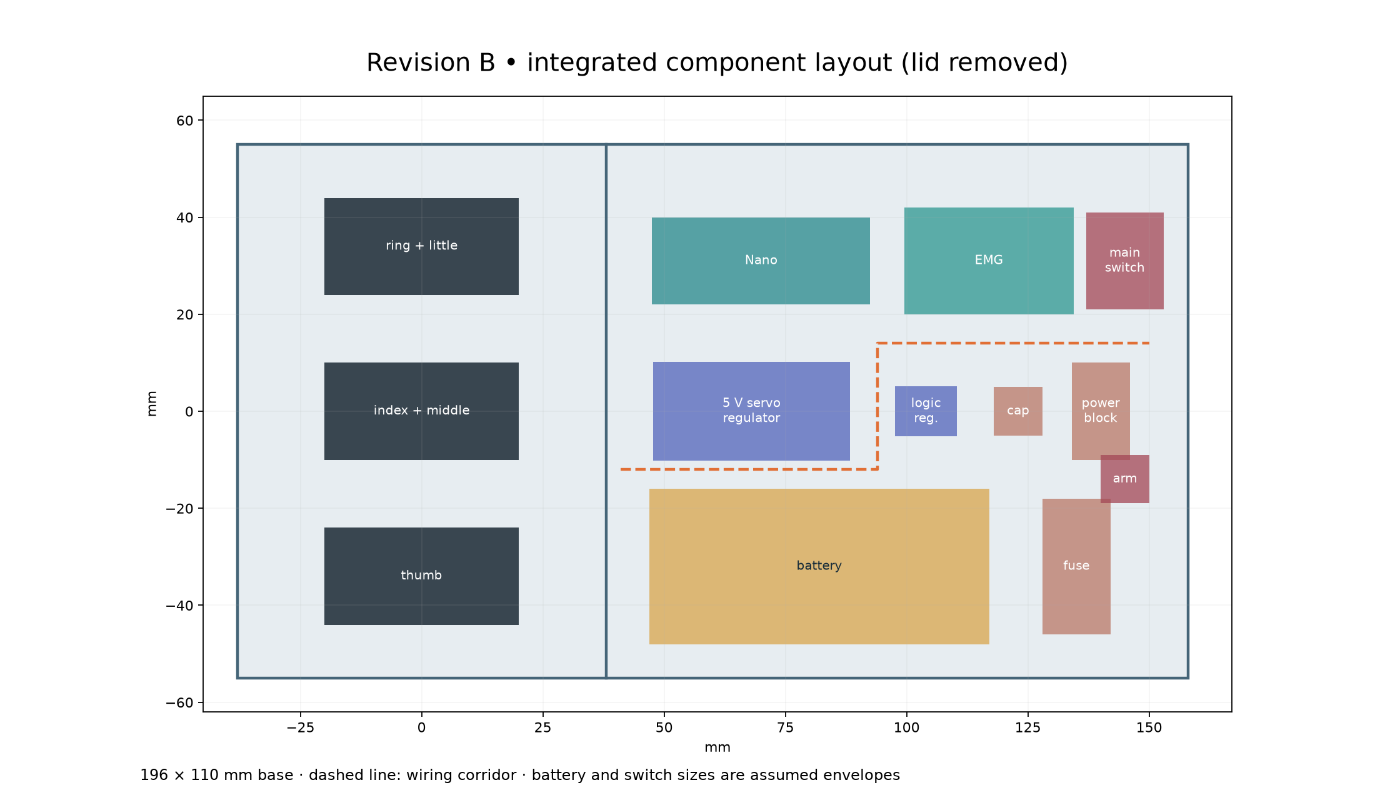
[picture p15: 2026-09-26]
cad/exports/integrated_layout.png

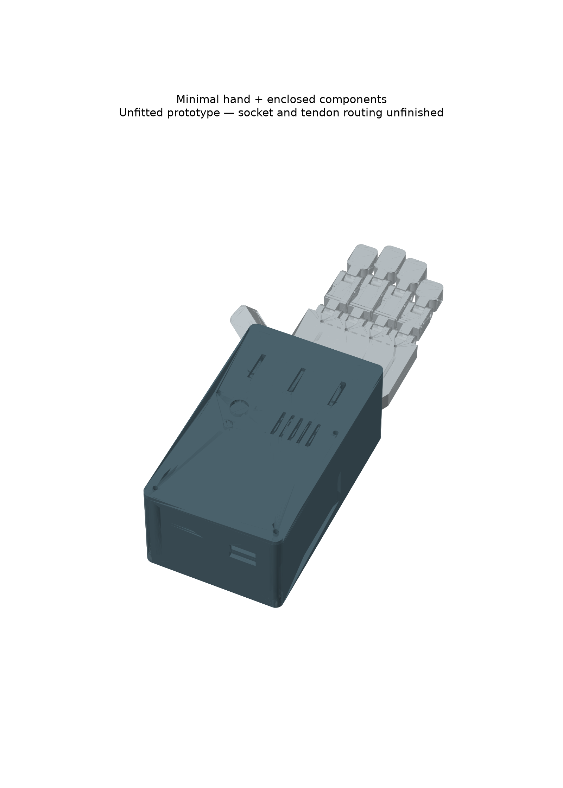
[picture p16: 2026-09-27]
cad/compact/exports/complete_preview.png

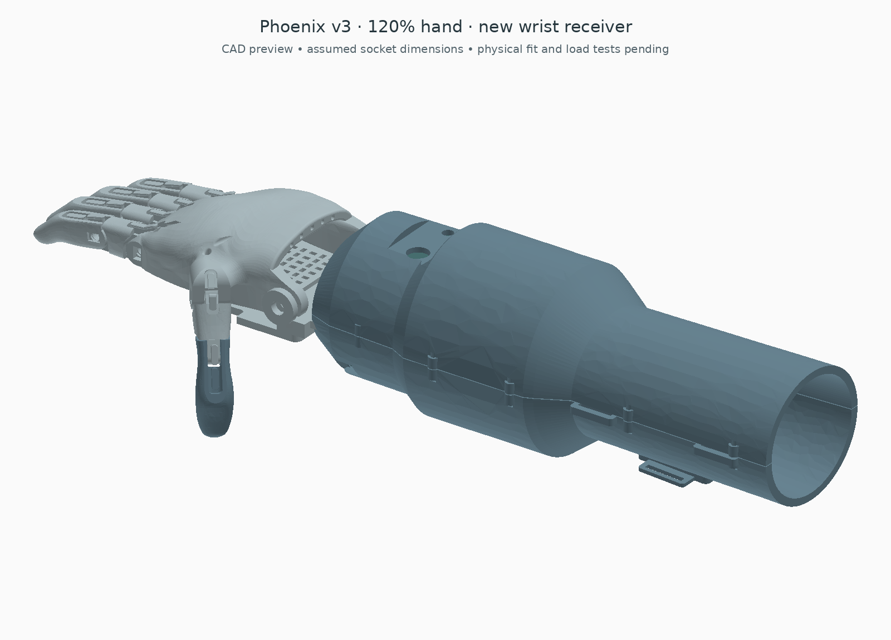
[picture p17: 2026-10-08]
cad/sizing/adapter_exports/sized_complete_preview.png

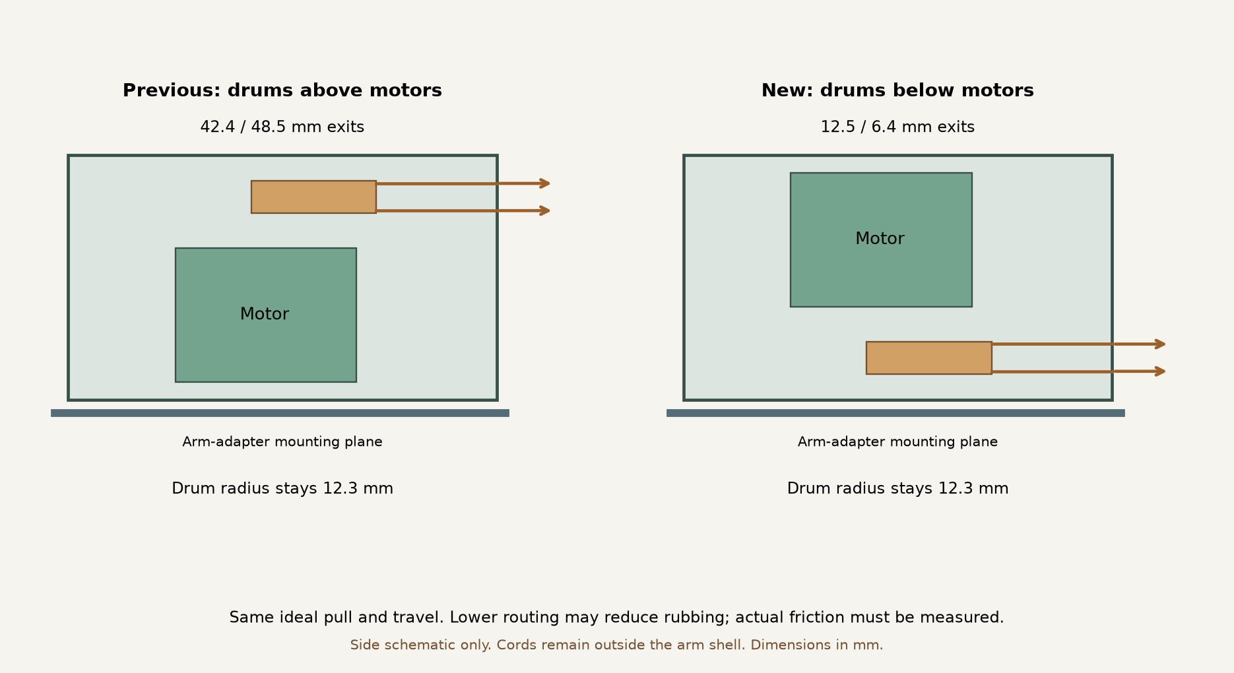
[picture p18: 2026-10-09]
cad/bottom_drive/exports/routing_comparison.png

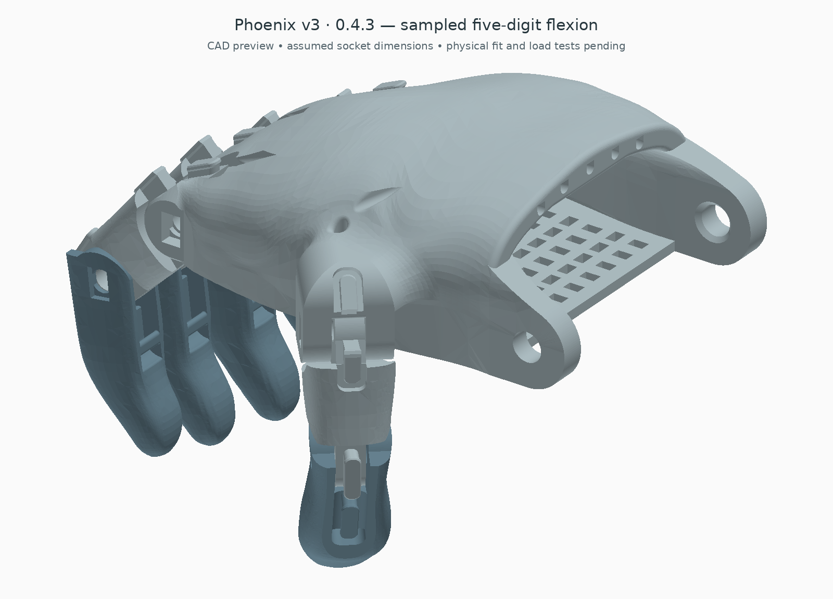
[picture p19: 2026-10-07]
cad/forearm/exports/flexion_preview.png

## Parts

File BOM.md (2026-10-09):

**Selected bottom-drive build:** use [the current procurement requirements](release/production/README.md#purchased-part-completion) and [current power/harness specification](docs/WIRING.md). Exact power components and owned-servo identification remain open. Lists below are historical or alternative variants.

The [bottom-drive variant](cad/bottom_drive/README.md#parts-and-assembly) adds twelve M3 motor-ear bolts/nuts and replaces the box base and structural cover. It retains the shorter replacement-servo requirement. Choose the complete matched variant, not a mixture of covers.

The latest lower-box option has its own [print and hardware list](cad/cuff_box_compact/README.md#print-and-hardware-selection). It uses three FT5425BL replacement candidates, an external supply and a new rigid adapter; do not mix its mechanical or power parts with the older generic-servo version.

**Separate cuff-box option:** use [its own print/hardware list](cad/cuff_box/README.md#hardware-and-electrical-notes). It has six new printed pieces, generic servo clearance assumptions and an external battery/fuse. Do not combine this enclosure with the integrated-forearm part list or assume its motor voltage is known.

**Historical 0.4.3 selection:** [forearm parts and hardware](cad/forearm/README.md#selected-parts-and-hardware), with the [replacement servo/power BOM](cad/slim/README.md#replacement-bom-and-power-changes). The shell includes internal motor, battery and board provisions; it replaces the separate box. Prices and the high-current supply components remain unselected.

**Optional 120% hand candidate:** use the [resized receiver guide](cad/sizing/ADAPTER.md). Replace the two corresponding baseline print parts; do not add duplicate shells or receivers.

| Candidate replacement / constraint | Quantity | Detail |
| --- | ---: | --- |
| `cad/sizing/adapter_exports/resized_receiver.stl` | 1 | Replaces the baseline palm receiver; fixed M4 forearm centres |
| `cad/sizing/adapter_exports/forearm_lower_head_clearance.stl` | 1 | Replaces the lower shell; two local screw-head clearance pockets |
| Forearm attachment M4 sets | 2 total | Existing count; heads must fit the 8 mm diameter × 2.5 mm allowance. Length, nuts and engagement remain to be selected against the print. |
| Hand, printed pins and wrist axle | 1 matching set | Example hand scale is 120%. Receiver wrist bore 7.6 mm; ear outer span 88 mm. Verify axle length and retention rather than reusing the earlier pin by assumption. |

Other baseline part quantities remain unchanged. This option is not included in the historical cost total below.

**Prototype 0.2.1 historical mechanical list:** [shells, receiver, connected thumb mount, cassette, inserts, guides, straps and fasteners](cad/bionic/README.md#added-hardware). This historical list does not describe the selected bottom-drive kit in [BUILD.md](BUILD.md). The older priced electronic/reference list below remains useful for component selection; its total does not price the new integration or patient-specific fitting.

# Bill of materials — three-servo prototype

One thumb servo, one index/middle servo and one ring/little servo. This historical hand is the [forearm-integrated Phoenix](cad/forearm/README.md); the costs below remain the revision B baseline. Compact-housing/cradle hardware and any fitted socket are not yet fully costed. This is the complete **reference build list**, including power and mounting consumables. Physical servo fit, hand sizing and load validation remain open; do not treat it as a purchase-ready matched kit.

**Historical 0.2.1 spool set (not bottom-drive):** print three `cad/compact/exports/single_groove_spool.stl` parts (6.75 mm high); keep two equaliser parts. Recheck M2 horn bolts and knot clearance for the thinner spool. Older double-groove spools do not fit the lowered roof.

**Historical 0.2.1 rounded-cover hardware:** four M3 through-fastener sets, with heads at most 6 mm diameter × 2 mm high to fit the recesses. Front/rear overall housing heights are 60/57 mm; measure from the recessed screw seat to the nut before selecting or trimming lengths. The older M3 × 45 revision B row below does not fit this housing. Inspect the 1 mm screw-seat thickness in a print sample. Switches need measured bushings and nuts for the 3 mm recessed panel. See [current housing notes](cad/compact/README.md).

[Right-arm attachment additions](cad/arm_interface/README.md#added-reference-bom): open saddle, separate electrode holder, webbing and cable restraint. These are not included in the older cost total; a fitted socket/liner remains unspecified.

[Wiring](docs/WIRING.md) · [CAD](cad/README.md) · [Firmware](firmware/README.md)

All monetary values below are **GBP planning allowances**, except the explicitly historical mechanical subtotal. They are not claimed as current quotes. They exclude shipping, taxes not included in a seller price, tools and labour. Owned items are included to show replacement cost.

| Item | Qty | Allowance each (£) | Line (£) | Selection / notes |
| --- | ---: | ---: | ---: | --- |
| Phoenix mechanical supplies | 1 | 21.52 | 21.52 | Screws, return bands, hand tendons, padding, fingertip grips and hand straps; existing five-hand purchase average |
| Phoenix printed parts | 1 | 8.00 | 8.00 | One hand set; filament allowance, scale dependent |
| Printed actuator add-ons | 1 | 9.00 | 9.00 | Integrated base ×1, lid ×1, spools ×3, equalisers ×2, fairleads ×3 |
| 25 kg·cm positional servo, 180° | 3 | 12.00 | 36.00 | Owned generic units; DS3225 only a reference; verify before purchasing |
| Classic Arduino Nano | 1 | 25.00 | 25.00 | A000005 / ATmega328P, 5 V; selected controller |
| DFRobot SEN0240 EMG kit | 1 | 45.00 | 45.00 | Owned; kit includes dry electrode, signal board, belt and leads |
| Pololu D24V90F5 servo regulator | 1 | 32.00 | 32.00 | Fixed 5 V; verify thermal/current headroom in enclosure |
| Pololu D24V5F5 logic regulator | 1 | 10.00 | 10.00 | Fixed 5 V / 500 mA class |
| Protected 2S battery pack | 1 | 18.00 | 18.00 | 7.4 V nominal, 1,000 mAh; ≥10 A discharge, balancing/undervoltage protection; reference CAD pocket assumes a 70 × 32 × 22 mm pack |
| Matching 2S charger | 1 | 20.00 | 20.00 | Match chemistry and pack connector; off-device charging |
| Metal servo horn | 3 | 3.00 | 9.00 | Spline must match actual servo; two holes must match spool slots |
| M2 bolts, nuts and washers | 1 | 2.00 | 2.00 | Six bolts plus six nuts/washers for three horns; length selected after horn fit |
| 4.8 mm cable ties | 6 | 0.10 | 0.60 | Three servo restraints plus three fairlead restraints; retain spares |
| 25 mm carrier straps | 2 | 2.00 | 4.00 | Separate from original hand straps; length to suit fixture/cuff |
| Carrier foam pad | 1 | 2.00 | 2.00 | 196 × 110 mm starting footprint; supplementary to hand padding |
| M3 lid hardware | 1 | 2.00 | 2.00 | Four M3 × 45 screws, nuts and washers; shorten and deburr screws to fit 41 mm stack |
| Insulating mounting pads and battery strap | 1 | 3.00 | 3.00 | Nominal 1 mm board mounting layer; 10 mm soft battery strap |
| PTFE liner | 1 | 2.00 | 2.00 | 2 mm OD / 1 mm ID, 0.5 m stock; cut guide inserts as needed |
| Additional braided tendon | 1 | 2.00 | 2.00 | 2 m allowance for actuator routing, nominal 0.5–0.8 mm; check knots and creep |
| Main switch | 1 | 3.00 | 3.00 | ≥10 A DC at battery voltage; CAD assumes 12 mm bushing and 16 × 20 × 20 mm body |
| 7.5 A fuse and holder | 1 | 3.00 | 3.00 | Fuse at battery; verify inrush and wire protection in testing |
| Arm toggle switch | 1 | 1.00 | 1.00 | Low-current SPST, D2 to GND; CAD assumes 6 mm bushing, 10 × 10 × 12 mm body |
| Power wiring and connectors | 1 | 6.00 | 6.00 | 18 AWG main leads, keyed ≥10 A connectors, distribution and insulation |
| Signal wiring / small perfboard | 1 | 3.00 | 3.00 | Short connections, strain relief, no breadboard motor-power path |
| Capacitors | 1 | 1.00 | 1.00 | 1,000 µF 10 V; 10 µF 10 V; 100 nF ceramic |
| Resistors | 1 | 0.20 | 0.20 | 220 Ω ×3, 1 MΩ ×1 |

**Planning total: £268.32, including £20 for the charger.** If all three servos and the complete EMG kit are already owned, subtract £81: remaining allowance £187.32. This is not a verified shopping total.

## Sources and quantities

- SEN0240 identity and kit contents: [DFRobot](https://www.dfrobot.com/product-1661.html). Manufacturer listing checked 26 September 2026: US$49.50; the £45 above is an allowance, not a currency conversion or UK quote.
- Nano dimensions and board identity: [Arduino](https://docs.arduino.cc/hardware/nano). Use the classic 5 V board, not a differently powered Nano variant.
- Servo reference dimensions/electrical data: [DS3225 datasheet](https://dsservo.com/d_file/DS3225%20datasheet.pdf). The owned model remains unknown.
- Servo regulator: [Pololu #2866](https://www.pololu.com/product/2866), manufacturer listing US$36.82 on the check date. Available continuous current depends on cooling/input voltage; "9 A" is not a guaranteed enclosure rating.
- Logic regulator: [Pololu #2843](https://www.pololu.com/product/2843), manufacturer listing US$8.95 on the check date.
- The original mechanical list records £107.59 for five hands, or £21.52 each rounded. This is the first row only; those hand supplies are not separately charged again. The carrier straps, padding and extended tendons are additional.
- Exact Phoenix pin/screw/band counts depend on the selected hand scale and official assembly instructions. The original-hand row is a supplies set, not a claim that these individual quantities have been verified. [Phoenix v3 source and instructions](https://hub.e-nable.org/p/devices?p=e-NABLE+Phoenix+Hand+v3).

No display is included in this simple version. The Nano LED indicates calibration/fault status; a screen would add code, wiring and space without helping the first mechanical test. A soldering iron, multimeter, force gauge, ruler/calipers, printer and suitable battery charger are needed; the charger is costed above, other tools are excluded.

Revision B includes an electronics enclosure and assumed battery pocket; see [integration details](cad/INTEGRATION.md). There is no completed wearable cuff. Regulator mounting must provide insulation and ventilation. Final part orders still require checking the owned servo spline, voltage and dimensions, plus battery/charger compatibility.

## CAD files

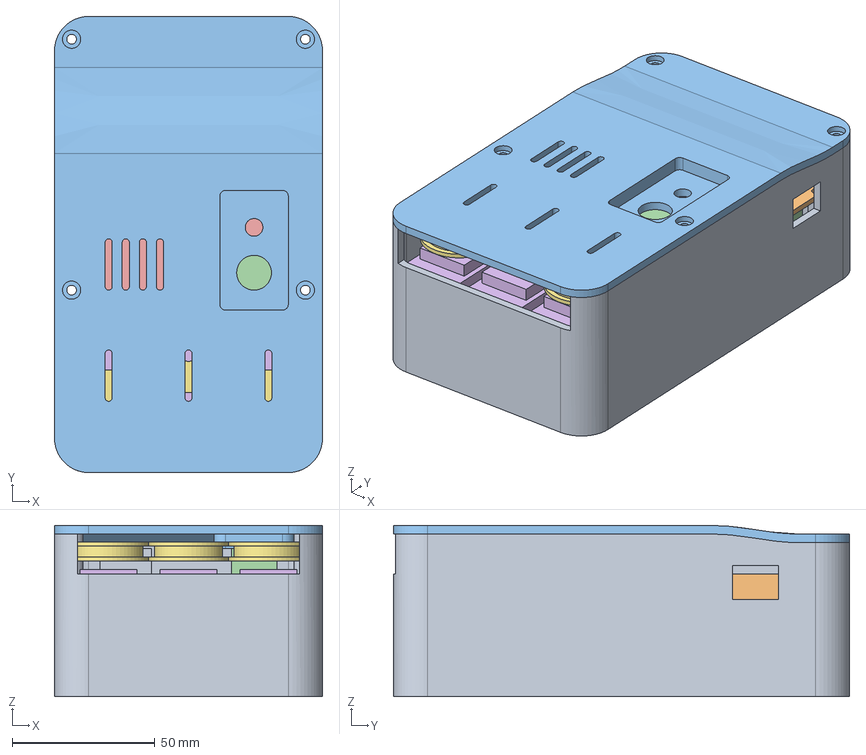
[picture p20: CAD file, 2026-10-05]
cad/compact/exports/compact_assembly.step
94.0 x 160.0 x 60.0 mm

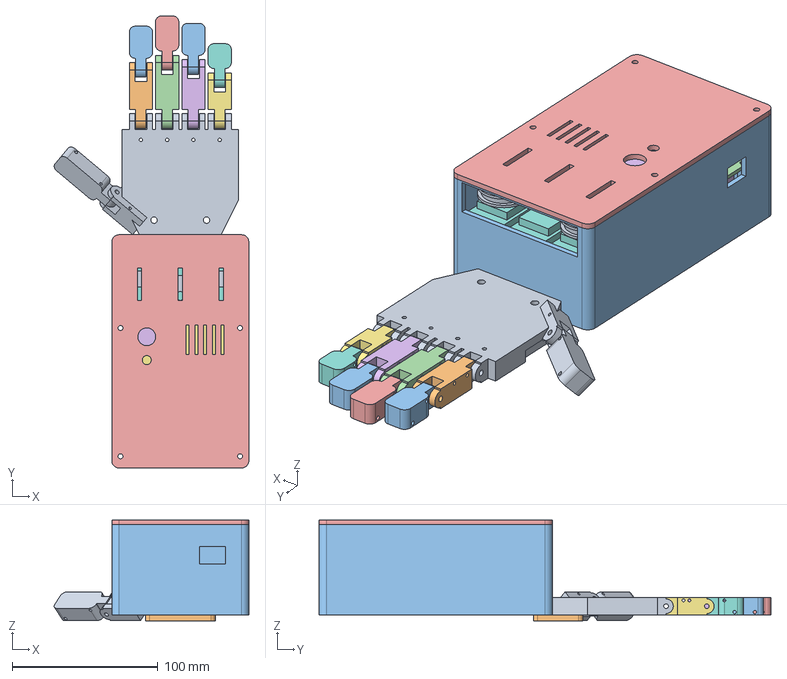
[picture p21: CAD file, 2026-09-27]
cad/compact/exports/complete_reference_assembly.step
133.5 x 310.0 x 69.0 mm

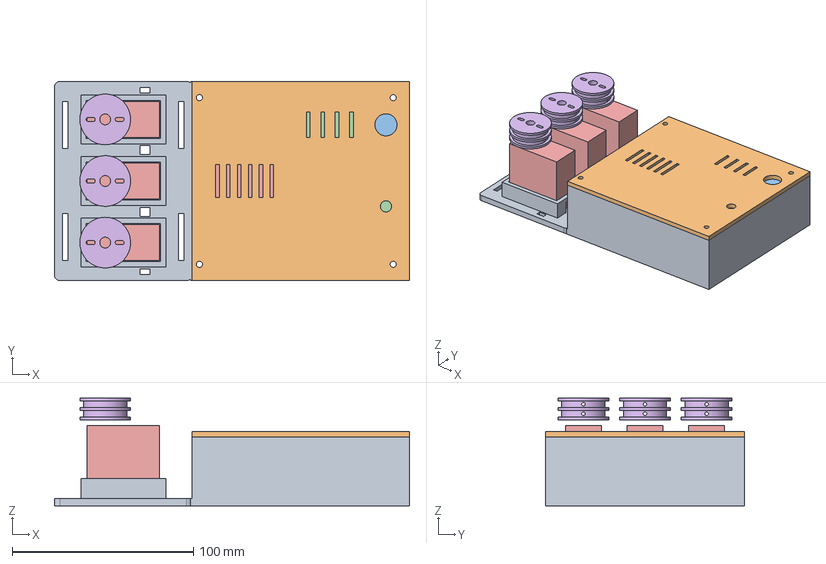
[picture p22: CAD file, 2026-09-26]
cad/exports/integrated_assembly.step
196.0 x 110.0 x 59.5 mm

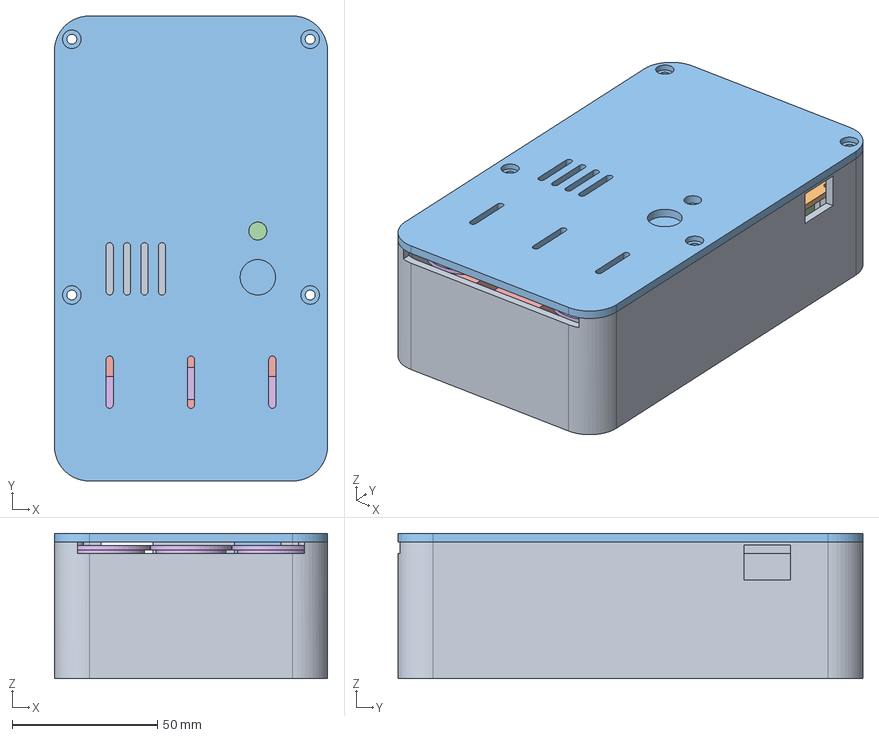
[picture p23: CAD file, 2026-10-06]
cad/slim/exports/compact_assembly.step
94.0 x 160.0 x 50.0 mm

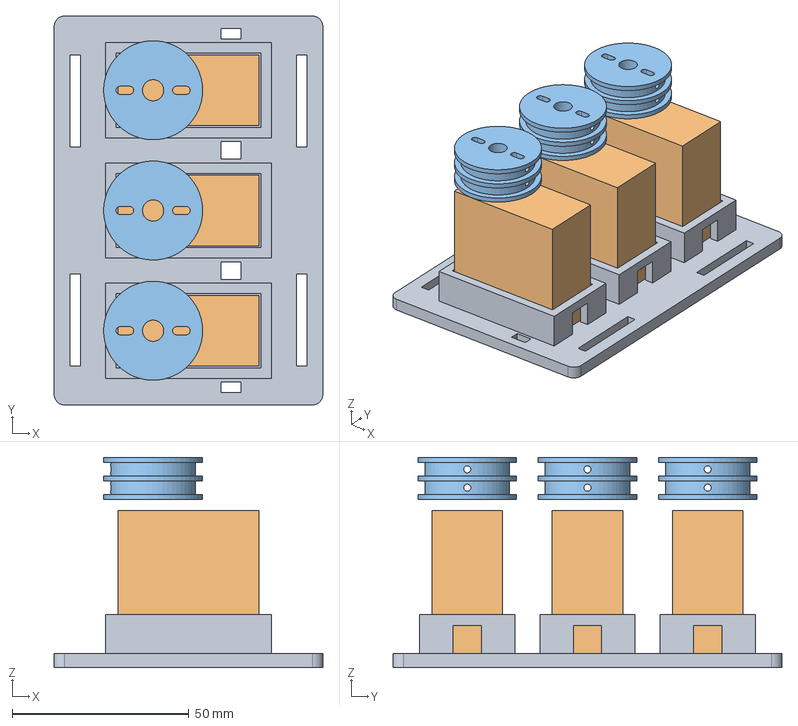
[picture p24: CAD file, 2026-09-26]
cad/exports/carrier_assembly.step
76.0 x 110.0 x 59.5 mm

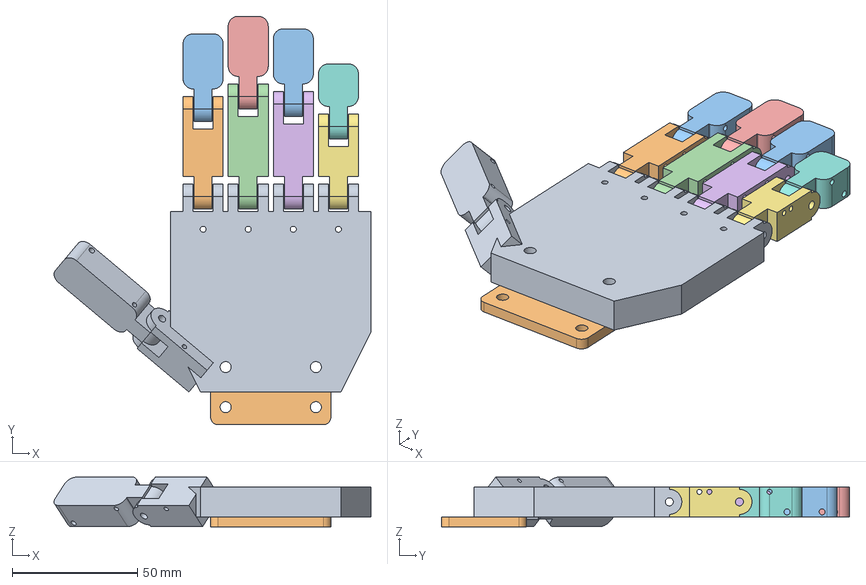
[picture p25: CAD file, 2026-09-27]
cad/compact/exports/minimal_hand_assembly.step
126.5 x 163.0 x 19.9 mm

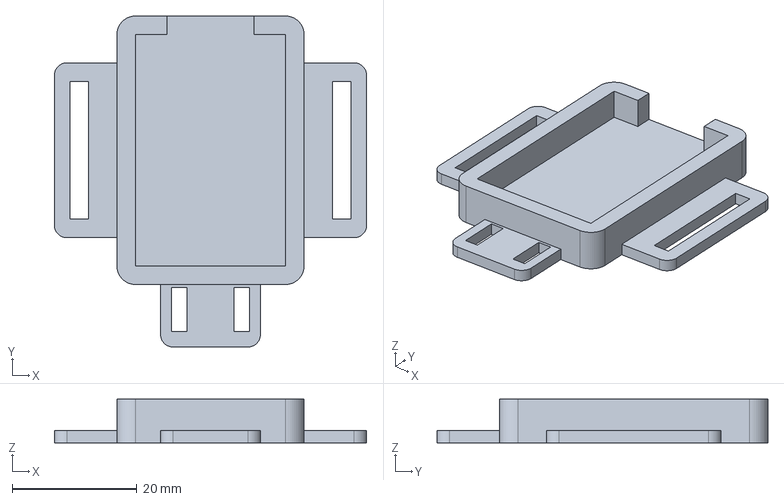
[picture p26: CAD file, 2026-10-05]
cad/arm_interface/exports/emg_band_carrier.step
50.0 x 53.0 x 7.00 mm

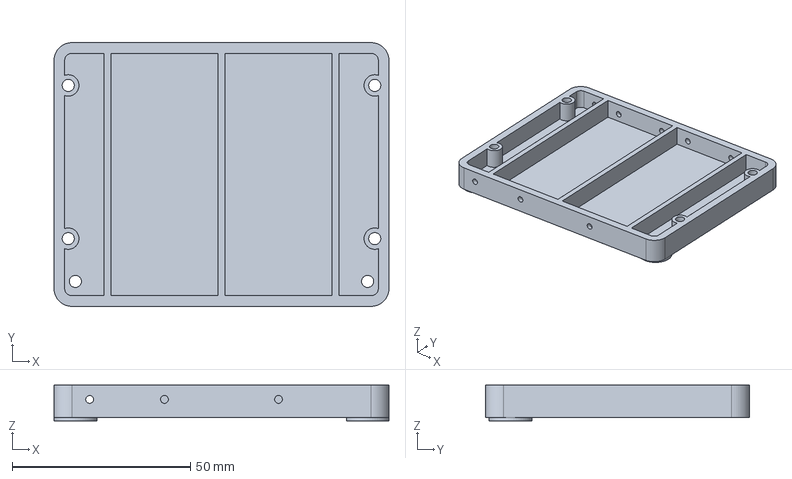
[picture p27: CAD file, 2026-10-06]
cad/bionic/exports/tendon_cassette_base.step
94.0 x 74.0 x 10.0 mm

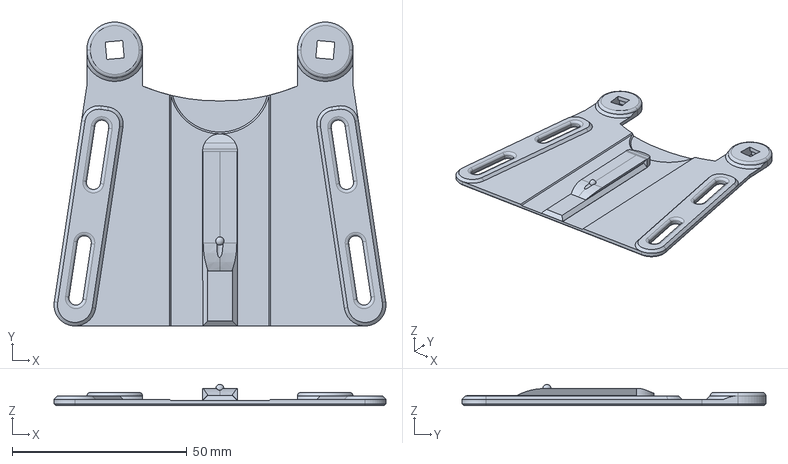
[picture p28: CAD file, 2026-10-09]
cad/bottom_drive/exports/original_flat_gauntlet_reference.step
95.0 x 87.0 x 6.07 mm

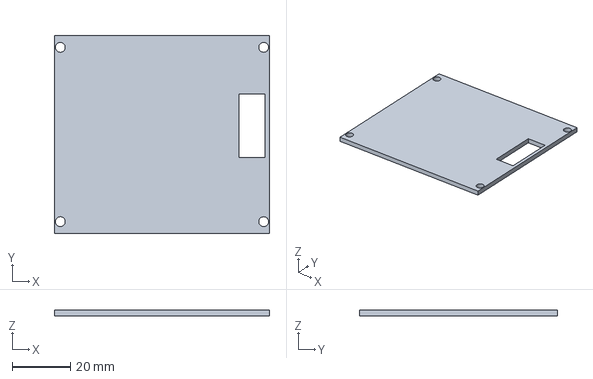
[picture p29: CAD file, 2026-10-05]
cad/compact/exports/compact_tray.step
74.0 x 68.0 x 2.00 mm

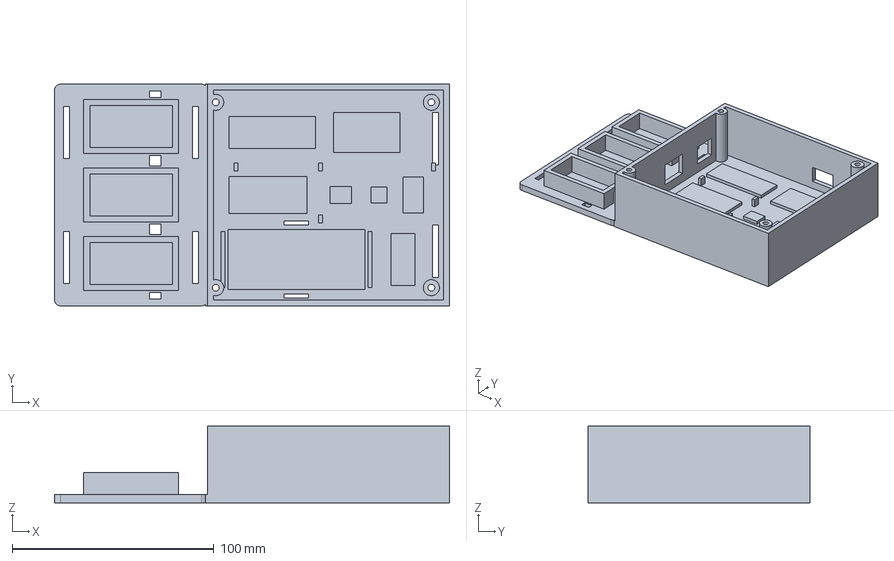
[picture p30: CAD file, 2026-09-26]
cad/exports/integrated_base.step
196.0 x 110.0 x 38.0 mm

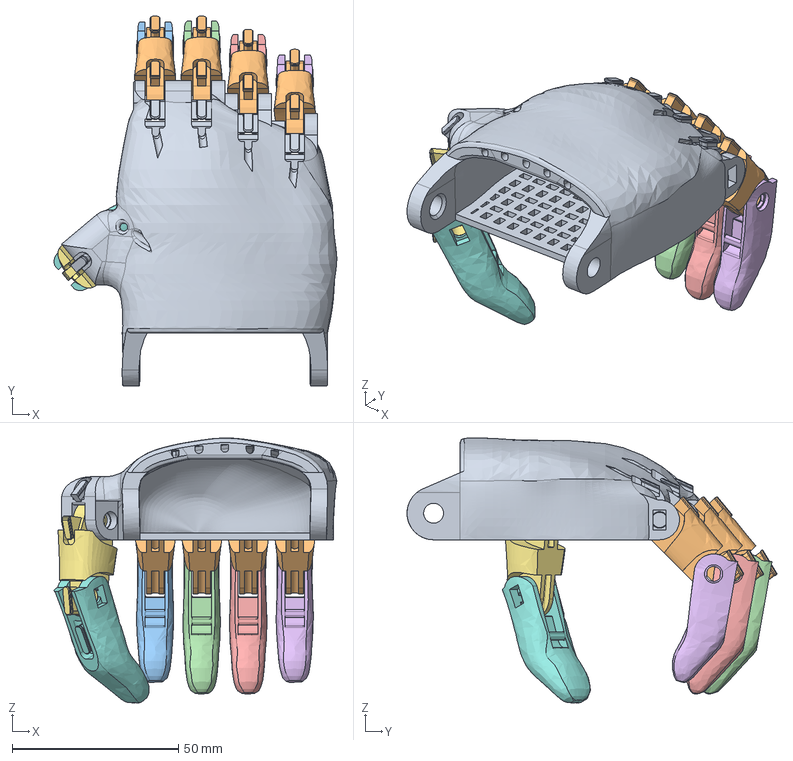
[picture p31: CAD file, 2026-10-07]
cad/forearm/exports/simultaneous_flexion_hand.step
85.1 x 111.3 x 79.7 mm

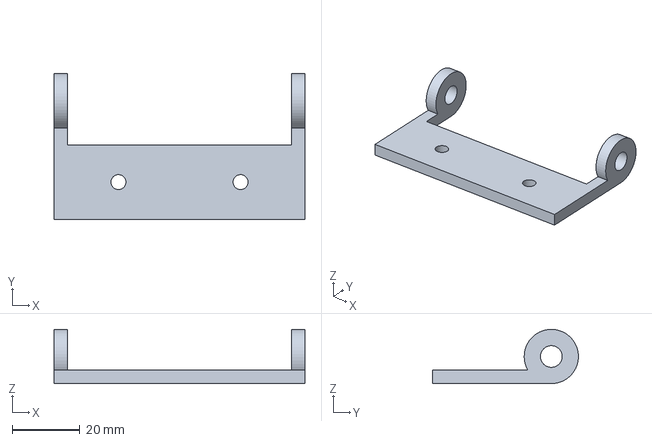
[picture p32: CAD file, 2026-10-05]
cad/phoenix_v3/exports/phoenix_wrist_cradle.step
74.0 x 43.0 x 16.0 mm

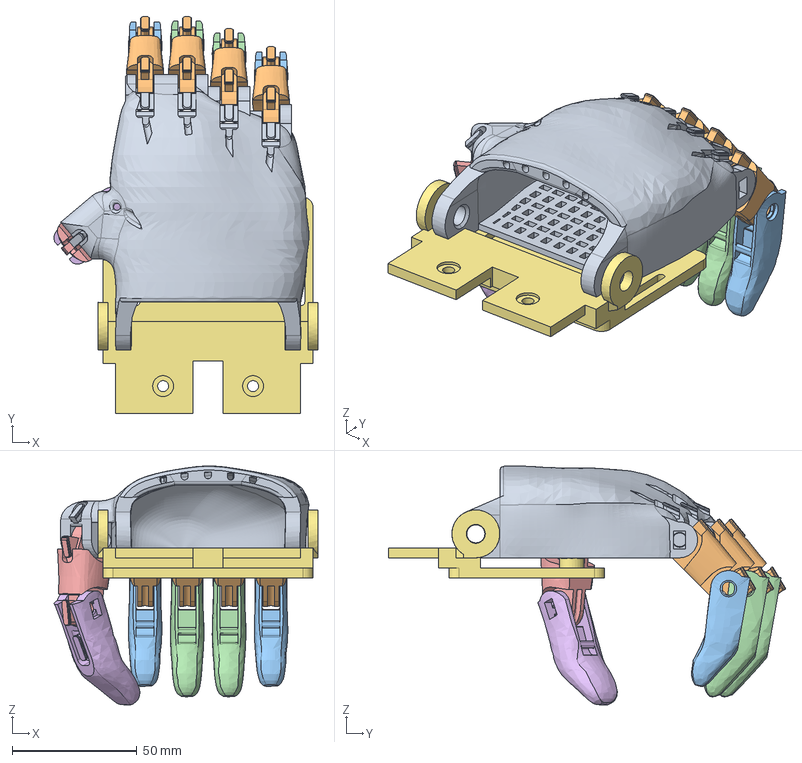
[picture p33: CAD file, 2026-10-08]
cad/sizing/adapter_exports/sized_flexion_hand.step
105.7 x 159.0 x 95.6 mm

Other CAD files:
cad/sizing/exports/limb_clearance_envelope.step
cad/slim/exports/feedthrough_lid.step
cad/upstream/phoenix_v3.step
cad/arm_interface/exports/right_open_saddle.step
cad/arm_interface/exports/emg_band_carrier.stl
cad/arm_interface/exports/right_open_saddle.stl
cad/bionic/exports/fixed_palm_receiver.step
cad/bionic/exports/fixed_palm_receiver.stl
cad/bionic/exports/housing_lid_with_feedthroughs.step
cad/bionic/exports/housing_lid_with_feedthroughs.stl
cad/bionic/exports/socket_dorsal.step
cad/bionic/exports/socket_dorsal.stl
cad/bionic/exports/socket_ventral_door.step
cad/bionic/exports/socket_ventral_door.stl
cad/bionic/exports/tendon_cassette_base.stl
cad/bionic/exports/tendon_cassette_cover.step
cad/bionic/exports/tendon_cassette_cover.stl
cad/bionic/exports/thumb_line_slider.step
cad/bionic/exports/thumb_line_slider.stl
cad/bionic/exports/wrist_guide_comb.step
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

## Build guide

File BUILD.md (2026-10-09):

# Current build entry point

**Selected engineering candidate: bottom tendon drive. Intended future use: a fitted device for one wearer. Status: NOT READY FOR FITTED USE OR PRODUCTION.**

Start with [one-wearer build preparation](release/production/README.md), then the [matched mechanical guide](cad/bottom_drive/README.md). Use the [current package verifier](release/production/package.py). Older integrated-forearm, upright-box and historical 0.2.1 kits are separate designs; do not combine their shells, receivers, covers or power specifications.

The current assembly retains the original Phoenix hand and uses three inverted FT5425BL replacement-servo references: thumb, index/middle, ring/little. The Nano and SEN0240 remain; battery/power supply is external. This does not identify the generic motors already owned.

Seven new print types make eight pieces. The complete STEP is an assembly reference, not a print-in-place file. The arm carrier remains a placeholder until wearer-specific socket, suspension and alignment are established by an appropriate fitting professional.

The most immediate mechanical gate is the horn/drum fastener stack: head projection ≤1.2 mm leaves only 0.6 mm nominal floor clearance. Verify real tolerances, fasteners and deflection before selecting the print. Full external tendon routing, wrist restraint, manual release, strength, electrical/thermal behaviour and durability remain unaccepted.

[Arduino setup and limits](firmware/README.md) · [Tendon measurements](TENDON-TEST.md) · [Open production/fitting gates](release/production/readiness.json) · [Validation evidence](VALIDATION.md)

The firmware is development code. Inversion requires unloaded winding-direction and endpoint calibration. No physical force feedback, validated electrode-loss detection or mechanical release is supplied by the control code.

**Before testing on a person:** start with [the staged bench procedure](docs/PRE-HUMAN-TEST.md), [current wiring](docs/WIRING.md) and [EMG mounting](docs/EMG-MOUNTING.md). The current physical starting point is the original Phoenix print only.

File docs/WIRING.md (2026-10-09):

# Wiring — bottom-drive candidate

**Updated 10 October 2026. Bench specification; not approval for worn use.** The original Phoenix hand is printed; the extension is not printed and the system is not wired. Identify the actual servos before applying power. This topology is for the FT5425BL replacement candidate, not unidentified generic 25 kg·cm servos.

Current wiring

## Connections

| Net | Connections |
| --- | --- |
| Source positive | External protected 2S pack → source fuse F1 → accessible DC main disconnect S1 → switched supply |
| Motor branch | Switched supply → branch protection/distribution → three FT5425BL positive terminals; **no 5 V servo regulator** |
| Logic branch | Switched supply → logic branch protection → separate 5 V regulator VIN |
| Logic 5 V | Regulator VOUT → classic Nano 5V and SEN0240 +; not Nano VIN |
| Common reference | Source negative, regulator GND, servo returns and logic return meet at distribution/star reference |
| Quiet return | SEN0240 − → logic return alongside Nano ground; servo current must not pass through this lead |
| EMG | SEN0240 A → Nano A0; 1 MΩ from A0 to logic GND is the existing experimental unplugged-signal bias |
| Electrode | Dry electrode → supplied lead → SEN0240 PJ-342 socket; never connect skin contacts directly to A0 |
| Enable | D2 → normally-open momentary hold-to-enable switch S2 → logic GND; internal pull-up enabled |
| Thumb | D9 → 220 Ω series resistor → thumb servo signal |
| Index + middle | D10 → 220 Ω series resistor → paired servo signal |
| Ring + little | D11 → 220 Ω series resistor → paired servo signal |
| Sensor decoupling | Candidate 100 nF ceramic and 10 µF polarized capacitor across sensor +/−, close to conditioner; ≥10 V ratings |
| Motor reservoir | Candidate 1,000 µF capacitor across distribution, ≥16 V rating; verify polarity, ripple rating, inrush and rail overshoot |

The diagram identifies nets, not physical connector pin order. Inspect delivered labels and confirm continuity with power removed. Use keyed, insulated connectors; distinguish motor supply from logic 5 V. Document harness pin numbers and wire labels before soldering. Do not distribute servo power through a breadboard or Nano pins.

## Power parts still requiring selection

The FT5425BL sheet reports 3.4 / 4.4 / 5 A stall current at 6 / 7.4 / 8.4 V: three units could demand 10.2 / 13.2 / 15 A, before logic current. These are fault-sizing inputs, not an instruction to deliberately stall motors. Keep the candidate rail within the evaluated 6–8.4 V range, including sag and transients; never infer another servo’s supply from its torque label. [FEETECH specification](https://www.feetechrc.com/Data/feetechrc/upload/file/20210810/6376418710101296552903409.pdf)

F1, branch protection, S1, battery/BMS, connectors, wire cross-sections and cable lengths are **not selected**. Select them as a coordinated system using measured demand, fault current, fuse time/current and let-through curves, conductor/connector limits, DC interruption ratings and thermal tests. A thin logic branch needs its own protection. The old 7.5 A fuse, ≥10 A switch and 5 V servo regulator are historical, not current selections. Do not simply enlarge a fuse.

The logic-regulator reference is Pololu D24V5F5 (5 V, up to 500 mA). Confirm headroom, heat, startup and noise under the actual load and lowest loaded input. Mounting allowance is not a confirmed purchased-board fit. [Pololu](https://www.pololu.com/product/2843)

SEN0240 accepts 3.3–5.5 V and outputs 0–3 V. The separate nominal 5 V logic rail and classic Nano A0 are the intended interface. Firmware filters the biased signal and averages squared activity. The 1 MΩ bias is not a validated electrode-contact detector. [DFRobot specifications and pinout](https://wiki.dfrobot.com/sen0240/)

## Cable routing and service

Mount the conditioner beside the Nano on the rear carrier. The 22 × 35 mm PCB has a 22 × 10 × 35 mm installed envelope in CAD; this does not prove the probe plug and bend fit. Use the rear-right side entry after checking the actual grommet/plug. Keep the lead away from drums, tendons and motor current loops. Fit insulating backing and removable retention through the carrier tie slots; do not tie over components or invent PCB mounting holes.

Restrain leads at the enclosure and electrode band so solder joints and skin contacts do not carry cable loads. Retain cover-removal slack and secure excess electrode cable outside moving parts without a loose snag loop. Verify the cover cannot pinch cables. See [EMG placement](EMG-MOUNTING.md).

## First electrical checks — no person connected

1. With battery, USB, electrode, motors and regulator outputs disconnected, inspect polarity, shorts, pinning and isolation from fasteners.
2. Verify regulator output with a current-limited source and dummy load before connecting logic. Set limits from actual parts and demand.
3. Fit Nano and conditioner with motor plugs removed. Firmware ships with SERVO_OUTPUTS_ENABLED = false; check processing and absence of pulses.
4. For fixture commissioning only, identify each motor, remove horns/tendons, establish limits and deliberately enable outputs. Test one motor, then three. Log rail minima/maxima, current, temperatures and resets. Use a test signal, not a person.
5. Check S1 cuts both branches and S2 removes commands. Neither proves the hand releases: geared motors can retain a grip without power. A separate tested mechanical release is required.

For USB programming, disconnect electrode, motor power and external logic power. Any later professionally reviewed body-connected session requires an appropriate isolated arrangement; the baseline proposal is battery operation with USB, charger and mains-linked instruments disconnected. Shared grounds are **not medical isolation**. Battery operation alone does not approve human testing.

Follow the [pre-human-test procedure](PRE-HUMAN-TEST.md). Never use a person as a load or jam fixture.

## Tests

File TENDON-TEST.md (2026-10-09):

# Measuring tendon force and travel

**Current bottom-drive build:** use [the fixed-groove measurement procedure](calculations/BOTTOM-DRIVE-PULL.md). First record hand-only readings, then repeat through the complete extension route. Older equaliser instructions below do not describe the current paired drums.

The first test is mechanical: leave the servo disconnected and find out how hard, and how far, each tendon has to be pulled. This measures the assembled hand, including the friction and return bands that are difficult to estimate from CAD.

## Equipment

- A force gauge or spring balance. A 0–50 N range is a useful starting point for one finger; use a larger range if the load approaches the limit.
- A ruler, a fine marker and a way to hold the palm firmly without distorting it.
- The actual tendon line, guides and return bands.
- A phone video can help match the force reading to finger position.

A luggage scale can give a rough reading, but check its minimum load and resolution. Some only lock a reading after a steady pull and will miss a short peak. A balance reading in kilograms is indicating kilogram-force here: multiply by 9.81 to obtain newtons. For example, 1.5 kg on the scale is about 14.7 N.

## One finger at a time

1. Disconnect power and unhook the tendon from the servo. Keep its route through the hand unchanged.
2. Secure the palm on the bench. Do not test with the hand strapped to a person.
3. Attach the scale to the tendon at the point where the servo would pull. Pull in the same direction as the planned drum tangent; pulling sideways changes the result.
4. Zero the scale in the test orientation. Take up loose slack without starting to close the finger, then mark the tendon against a fixed reference.
5. Pull slowly until the finger reaches its intended closed position. Stop at normal closure, not after forcing it against a hard stop.
6. Record the largest reading during the movement, not just the reading at the end. Note any sticking or sudden jumps.
7. Measure how far the tendon mark moved. This is tendon travel; it is not fingertip travel.
8. Release and check that the finger reopens. Repeat five times. Keep the highest measured pull for sizing and retain all readings.
9. Repeat at approximately the intended closing speed. The slow test alone does not capture acceleration or all dynamic effects.

If the scale itself stretches, measure the tendon mark relative to the hand, not the movement of the scale handle.

| Finger | Trial | Peak scale reading, kgf | Peak force, N | Tendon travel, mm | Return-band setup / sticking |
| --- | --- | --- | --- | --- | --- |
| | 1 | | | | |
| | 2 | | | | |
| | 3 | | | | |
| | 4 | | | | |
| | 5 | | | | |

## The two-finger test

For a first approximation, add the highest separate readings. This is conservative if their peaks occur at different points, but it cannot show how the coupling behaves.

Next, test the intended coupling or use a temporary crossbar that pulls both lines in the intended direction. If it does not reproduce the final geometry, record that difference. Watch whether one finger finishes closing first and whether the other still moves without excessive line tension.

Repeat around a chosen object and record its size and shape. Stop when contact is established; do not pull harder just to obtain a high reading. This checks closure around that object. Quantifying grip or object retention is a separate test.

## Use the measurements

Because the scale is at the servo end and the tendon passes through the actual guides, the reading already includes those routing losses. Do not add the assumed 40% friction loss a second time.

For two grooves of equal effective radius:

    torque_needed = 1.5 × (F1 + F2) × r

F is in newtons, r is in metres and torque is in N·m. The factor 1.5 is a provisional load margin.

If radii differ, use 1.5 × (F1 × r1 + F2 × r2). A lever or differential coupling needs its own force/displacement ratio.

### Worked example — invented numbers to show the method

Suppose finger A peaks at 1.2 kgf, finger B at 1.5 kgf, and the drum radius is 10 mm:

    total pull = (1.2 + 1.5) × 9.81 = 26.49 N
    torque with margin = 1.5 × 26.49 × 0.010 = 0.397 N·m

The DS3225 reference has a 5 V stall specification of 21 kgf·cm. Using the provisional 40% working allowance gives 0.824 N·m. This example is below that allowance, but actual servo temperature, current and duty still need checking.

For travel, suppose the measured requirement is 24 mm and we reserve 3 mm for slack/stretch. Over a calibrated 160° sweep:

    minimum radius = (24 + 3) / (160 × pi / 180) = 9.7 mm

A 10 mm drum would just meet that illustrative travel requirement. If the real requirement is longer, increase the radius and repeat the torque calculation. Keep line winding in one layer so the radius stays predictable.

## Send back these results

- Finger names, maximum force and travel for each.
- Paired maximum force and whether either finger stops early.
- Return-band arrangement and any sticking.
- Drum radius and available angular movement, if already built.
- Servo label or old order details if they turn up.

These readings will let us replace assumptions in [SERVO-SIZING.md](SERVO-SIZING.md) with measurements.

## Calculate from your measurements

Use the [measured-pull worksheet and checker](calculations/MEASURED-PULL.md). It checks both force and travel, rejects invalid inputs, and keeps missing measurements unresolved. Measure at the actuator end to include routing losses once.

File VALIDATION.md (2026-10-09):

## Pre-human-test preparation — 10 October 2026

The user confirmed only the original Phoenix v3 hand is printed; extension and wiring are not built. No physical gate is closed.

Updated the bottom-drive wiring diagram and net table: direct candidate motor rail, separately protected 5 V logic branch, retained A0/D2/D9/D10/D11 mapping, cable/conditioner placement and unresolved power-part ratings. The SVG/PNG was rendered and visually inspected. Actual connector fit and skin contact remain untested.

Firmware now ships with servo outputs disabled. With outputs explicitly enabled for fixture tests, a post-calibration 50 ms switch release is required before enabling; startup with the switch held is inhibited. Disarm/fault detaches at the next processed sample instead of waiting for the servo update. This is not a hardware safety circuit, force feedback or mechanical release.

Added a fixed-groove torque/travel screen, blank actual-measurement template and regression tests. It sums paired torque requirements and rejects non-overlapping common travel; full-route data and confirmed hardware are still required. Historical equaliser instructions are labelled separately.

Fresh controller/filter/calculation tests and both disabled/enabled Nano builds are recorded in release/production/software_checks.txt, with distributed firmware hashes. These are software checks; no board upload, timing measurement, physical movement, release test or human trial occurred. CAD geometry is unchanged; existing CAD reports are checked for matching hashes during packaging, not claimed freshly regenerated.

Added a staged pre-human-test procedure, mounting instructions and blank bench record. Mechanical release design, identified hardware, final power BOM, qualified printed extension, physical tests and professional fitting review remain required. Production and fitted-use status remains blocked.

# Validation record — 26 September 2026

## Resized receiver candidate — 8 October 2026

`cad/sizing/build_adapter.py` checks the 120% example against the existing fixed hardware. A new receiver preserves the two M4 forearm centres; a revised lower shell adds two local head-clearance pockets. The CAD checks include one-solid/mesh validation for both replacements, cylindrical bore positions, bearing material beneath the screw recesses, static interference, thirteen sampled hand poses against the receiver/fixed components and complete/open export matching. Results and source/output hashes: `cad/sizing/adapter_exports/adapter_checks.json`. Original hand-to-hand checks are inherited by uniform scaling rather than rerun; no loaded or fitted-use acceptance is claimed.

`tests/receiver_geometry_test.py` checks valid receiver solids and fixed bolt geometry at 90% and 140%, and rejects out-of-range or NaN scales. Those boundary tests do not validate complete assemblies at those sizes. The original 0.4.3 assembly remains separate.

## Anthropometric sizing study — 7 October 2026

`cad/sizing` exports a uniformly scaled original hand and a separate adjustable limb/liner clearance envelope. It checks STEP bounds and volume scaling for all eleven corrected hand solids, and tests the envelope/resized hand against the existing hardware geometry. The seven arithmetic tests cover missing measurements, signed anatomical registration, length/width mismatch and stroke limits. The report never labels these geometric checks as patient fit. The illustrated 120% hand needs a new receiver; the existing forearm and its motion acceptance remain at 100%. See `cad/sizing/README.md` for exact scope.

## 0.4.3 follow-up — 7 October 2026

- `closure_checks.json`: thirteen simultaneous five-digit poses clear the palm, each other, wrist support and both arm halves at the 0.001 mm³ reporting threshold. The trajectory reaches 60° MCP / 70° PIP, with thumb root −90° / tip 40°. These are samples, not continuous or loaded-motion acceptance.
- `assembly_checks.json`: matches all eleven hand solids in the complete, open and close-up STEP exports by bounds, centre and volume, with documented numerical integration tolerances. Source, STEP and preview hashes prevent stale packaging.
- `servo_reference.py`: manufacturer drawing-based case, ears and shaft; spools moved from a 10 mm to the specified 11.5 mm offset. Rebuilt static assembly and seven printable parts pass existing checks. Horns, wiring and actual bought-part fit are not validated.
- `tests/pull_sizing_test.py`: checks torque units, force/travel trade-offs, invalid inputs and missing measurements/calibration. The supplied measurement template remains unresolved; no physical readings were invented.

## Current forearm integration — 6 October 2026

The current selection is [cad/forearm](cad/forearm/README.md). Seven new parts are valid single solids with watertight, positive-volume STL exports. The complete static assembly has no reported part/envelope overlaps above 0.001 mm³. Equipment and both shell halves clear the reserved socket lumen. The lower shell includes a battery cradle and two under-floor strap passages; controls are recessed in the upper shell. Results: `cad/forearm/checks.json`.

On 7 October 2026 the original v3 right-hand placemat was retrieved and visually inspected alongside the original STEP. The short/long/long/short finger order is confirmed. The thumb now uses the native palm pin axis and the centre of its 6.5 mm inner fork gap. The displaced fork is removed; only the added support is relieved. `cad/forearm/layout_checks.json` records eight clear thumb poses between −60° and −90° root rotation, with 10°/30° tip bend. These are discrete CAD samples, not full thumb opposition, pin-fit or physical validation. Source geometry remains unchanged.

`cad/forearm/motion_checks.json` records 18 equaliser poses, three thumb-slider poses and a 45° MCP / 15° PIP four-finger pose. The discrete mechanism samples span 38 mm and include 6 × 2 mm tendon-base screw-head allowances. No continuous sweep, moving-cord clearance or installed-fastener acceptance is claimed.

**Fingertip inversion fixed in 0.4.2:** all five distal source solids were still upside down in the previous assembly. They now roll 180° longitudinally, placing their own return-band tabs dorsally. The previous reported 30–60° PIP interference came from that placement error. Forty four-finger adjacent-part checks through 60° bends now remain below 0.001 mm³ (maximum approximately 0.000895 mm³). The displayed rest PIP angle is 10° because corrected 0°/5° poses contact the original stop surfaces. `cad/forearm/exports/finger_motion_diagnostic.json` records the corrected samples. This does not validate pins, full continuous closure or loaded operation.

The assembly assumes 160 mm from residual-limb end to wrist. Bought-part lead/connector geometry, high-current component selection, straps, print strength, patient-specific fit and all hardware tests remain open. Firmware is unchanged; previous compile/control-test records remain historical. Rebuild commands are in the current guide.

## Completed

- Arduino CLI build: `arduino:avr:nano:cpu=atmega328`, AVR core 1.8.8, Servo 1.2.2. Result: 7,228 bytes flash (23% of 30,720), 653 bytes global RAM (31% of 2,048).
- Host C++ control tests: calibration duration, activation debounce, relaxation, disarm/rearm, three-second timeout, rail-fault handling and arithmetic range pass.
- Host integration test using the actual included OYMotion filter: synthetic resting baseline → 80 Hz activity → resting baseline causes open → close → open. This is a synthetic software test, not a human EMG recording.
- Official Phoenix STEP downloaded from the e-NABLE catalogue link, imported successfully as 32 solids. Upstream SHA-256 recorded in `cad/README.md`.
- CadQuery 2.8.0: all four generated printable parts are valid single solids. STL exports have positive volume and are watertight. Results: `cad/cad_checks.json`.
- Reference rectangular servo bodies have zero volume intersection with the carrier. This excludes horns, ears, connectors, ties and actual manufacturing tolerances.
- Wiring diagram and CAD preview images rendered and visually inspected.

- Revision B integrated base and lid pass valid-single-solid and watertight-positive-volume mesh checks. Ten electronic/battery/switch envelopes have no detected intersection with the base, lid or each other. Base/lid fit and servo/spool-to-base clearance checks pass. See `cad/integration_checks.json` and the scope limits in `cad/INTEGRATION.md`.

- Three optional fit coupons pass single-solid and watertight-positive-volume checks; see `cad/coupon_checks.json`.

## Not performed

No board upload, on-device timing measurement, real EMG capture, servo load/temperature/current test, physical print fit, structural analysis, grip test or wearable assessment has been performed. No clinical or production acceptance is claimed. BOM prices are planning allowances, not a completed set of supplier quotes.

## Reproduce

```
arduino-cli compile --fqbn arduino:avr:nano:cpu=atmega328 firmware/ProstheticHand
c++ -std=c++11 tests/control_test.cpp -o /tmp/control_test
/tmp/control_test
c++ -std=c++11 tests/filter_test.cpp firmware/ProstheticHand/EMGFilters.cpp -o /tmp/filter_test
/tmp/filter_test
python cad/build.py
python cad/integrate.py
python cad/fit_coupons.py
python docs/draw_wiring.py
python docs/make_bom.py
```

Install Arduino Servo through Library Manager. CAD generation uses CadQuery 2.8.0, trimesh and matplotlib; wiring rendering uses CairoSVG. The physical build tasks are tracked in `TODO.md`.

## Revision C geometry study — 27 September 2026

The original minimal-hand and compact-pack scripts export 15 valid single-solid printable part variants (including both mirrored palms). STL meshes are watertight with positive volume. Reference component/fixture pairs, the static hand assembly and the hand-to-housing assembly have no detected volume clashes. Each long finger was checked against its adjacent link and palm at synchronized 0/15/30/45/60-degree joint positions; thumb-to-palm checks use the same samples. These checks pass after adding thumb relief. They do not establish independent-joint swept clearance, tendon routing, grip function, structural strength or arm fit. See `cad/compact/*checks.json` and [revision C scope](cad/compact/README.md).

## Phoenix v3 restoration — 27 September 2026

The selected hand now uses the 32 solids extracted from the hash-verified official Phoenix v3 STEP. No original palm/finger geometry is altered. The new wrist cradle passes valid-single-solid and watertight-positive-volume STL checks. The reference view uses the compact enclosure and original hand parts; the thumb is deliberately exploded because its joint orientation is unresolved. Sub-0.001 mm³ source joint contacts are reported separately from larger clashes. Some diagnostic source STL conversions fail watertightness checks, so the repository supplies source STEP parts and links to the official printable STLs rather than distributing those conversions. See `cad/phoenix_v3/checks.json`. No physical fit or articulation acceptance is claimed.

## Rounded enclosure — 5 October 2026

The compact base, tray and curved lid pass valid-single-solid and positive-volume watertight STL checks. All modelled component/fixture pairs have zero reported volume clashes. The rebuilt Phoenix reference assembly reports no larger static collisions; inherited source contacts and source mesh limitations remain recorded separately. Both assembly and internal-layout previews were visually inspected. Original Phoenix source geometry remains unchanged.

The housing has 12 mm outer corner radii, a 65 mm motor-end roof falling to 59 mm at the rear, a 5 mm recessed switch panel and 2 mm screw-head recesses. These are CAD dimensions, not measured print results. Thin screw seats, actual switch/head fit, curved-cover support removal, cable clearance and cooling require physical checks. Servo and battery envelopes remain assumptions. No firmware changes or new hardware tests were performed in this revision.

## Lower single-groove revision — 5 October 2026

Supersedes the preceding rounded housing dimensions. Current front/rear roof heights are 60/57 mm. The base, tray, lid and new 6.75 mm single-groove spool are valid single solids with positive-volume watertight STL meshes. Modelled component/fixture pairs have no volume collisions. The new spool retains a 12 mm groove-floor radius; measured hardware and line-layer build-up are not represented.

`python3 calculations/tendon_forces.py` regenerates the force/travel report and JSON using the DS3225 5 V reference, explicit working/margin assumptions and 40/60/80% routing-efficiency scenarios. The 60% case gives 13.39 N per paired finger and 34.35 mm take-up at an illustrative 160 degrees. Actual closure tension, fingertip force, structural strength and thermal duty remain unmeasured. Firmware is unchanged.

The rebuilt Phoenix reference assembly reports no larger static collisions. The current exterior preview and force/travel plot were visually inspected. Inherited source mesh limitations and the deliberately exploded thumb remain unchanged.

## Right-arm interface concept — 5 October 2026

The open saddle and EMG-band carrier pass valid-single-solid and positive-volume watertight STL checks. The new parts have no modelled volume collisions with one another, the probe envelope, or the complete current Phoenix/housing assembly. The front housing bridge includes relief around the existing cradle plate. The saddle does not intrude into its placeholder lumen. These are geometric checks, not tissue-pressure, suspension or strength tests.

Personal-statement v4 was read locally from current IWA text and its embedded preview. DFRobot confirms a 22 × 35 mm dry-electrode board and placement along muscle direction on exposed skin. Electrode thickness, contact protrusion, residual-limb dimensions, straps, liner and anatomical alignment remain unverified. No patient-specific socket or wrist lock has been completed. Firmware and earlier force calculations remain unchanged.

## Prototype 0.1 package finalisation — 5 October 2026

Selected parts and firmware sources are listed with SHA-256 hashes in `release/manifest.json`. `release/package.py` verifies required files and existing collision reports and checks ZIP integrity. This is packaging validation, not a new CAD solve or physical acceptance. No geometry or firmware changed in this finalisation.

Host control tests passed again: calibration, debounce, release, arming, timeout, fault handling and arithmetic. The real included OYMotion filter/controller integration test passed with synthetic rest/contraction/rest input. The earlier Arduino compile result remains historical; no fresh board compile or upload was performed. Current hand-scale, thumb, wrist lock, tendon/equaliser retention, real component fit and individual socket fitting gates remain open in `BUILD.md`.

## Integrated right bionic revision 0.2 — 5 October 2026

The source STEP SHA-256 remains verified and all original palm/finger shapes are retained. The new connected thumb fork translates the thumb root 18 mm outward and 6 mm upward; root relief is made in the added fork only. The eight new printable variants pass valid-single-solid and positive-volume watertight mesh checks. The complete static assembly has no reported volume clashes above the script's threshold. Equalisers pass 18 sampled combinations (three travel positions, ±30/0° tilt); thumb MCP samples 0/15/30/45° pass against the fork, fixed assembly, receiver and guide comb. A separate final STEP intersection check finds 0 mm³ overlap between the independent EMG carrier and each of the dorsal shell and ventral door. These are sampled geometric checks, not continuous full-joint articulation, structural testing or grip acceptance.

Nano firmware compiles freshly with `arduino:avr:nano:cpu=atmega328`, AVR core 1.8.8, Servo 1.3.0: 7,228 bytes flash, 653 bytes global RAM. Host control and actual OYMotion filter/controller integration tests pass. The averaging helper was extracted for clarity; its 32-sample mean and control behaviour are retained. No board upload or real EMG capture was performed.

The current statement v4 text was reread locally and its design requirements are traced in `cad/bionic/README.md`. Hardware clearances remain nominal, socket dimensions remain placeholder values, flexible lines/straps and fastener insertion are not fully modelled, and actual release, fit, load, noise and thermal tests remain required. Package integrity checks and selected-file SHA-256 hashes are recorded by `release/package.py`.

## Small exterior refinement 0.2.1 — 6 October 2026

The cassette now has continuous rounded 3 mm walls with 5/2 mm outer/inner corner radii, a 0.8 mm top-edge chamfer and 6.2 mm diameter × 1 mm-deep screw-head recesses. The added thumb-support plate has 5 mm corner radii. All eight printable parts remain valid single solids with watertight, positive-volume meshes. All eight exported bounding dimensions and assembly Z positions agree with 0.2 within 0.001 mm. Source hand hash, socket parameters, thumb bore, 38 mm slider travel and sampled angles are unchanged.

The rebuilt assembly has no detected static volume collisions; the independent EMG carrier is now included in the routine pair checks. All 18 equaliser poses and four sampled thumb-root angles pass. Firmware, servo/spool geometry, component placement and force calculations are unchanged; no repeat firmware build or hardware test was needed for this geometry-only refinement. Recessed screw seating, joint motion under load, print strength and patient fit remain unverified.

## Smaller-part layout candidate — 6 October 2026

`cad/slim/build_pack.py` passes valid-single-solid and positive-volume watertight checks for its four exports, including the retained spool geometry. Component-envelope/fixture pair checks pass after adding local relief for the conservative servo-ear envelopes at the front inner corners. The added feed-through lid also passes solid and watertight checks.

`cad/slim/integrate.py` retains 16 hand/interface solids, replaces the old component pack and lowers the complete cassette by 10 mm. No static pair intersections above 0.001 mm³ are reported. Source hand identity remains recorded; cassette internal sampled clearance is inherited through rigid translation, not rerun as a new articulation study. The final CAD and internal layout previews were visually inspected.

Housing height is 50 mm, compared with 60 mm previously; housing-plus-cassette height is 63 mm versus 73 mm. Width/length remain 94/160 mm. Force/current calculations use FEETECH manufacturer data and explicit margins, with source links in the candidate guide. Firmware is unchanged and was not recompiled for this packaging study. Actual servo mounting, headerless Nano clearance, high-current protected battery circuit, flexible routing, thermal/load testing and individual socket fit remain unverified.

## Separate strap-on cuff box — 8 October 2026

This is a separate layout, not a revision to the integrated forearm. The original Phoenix hand and flat source gauntlet are unchanged. Five new print types (six pieces) pass valid-single-solid and positive-volume watertight STL checks. Static component/cord checks, expanded servo-ear keep-outs and the nominal cuff-volume clearance report no intersections above 0.001 mm³. Three sampled finger/thumb poses clear the new enclosure. Recovered shaft/drum axes agree, and exported STEP component bounds match after reimport. Exterior and open previews were visually inspected. Results and source/output hashes are in `cad/cuff_box/exports/checks.json`.

The case body is 94 × 96 × 71.5 mm; strap ears increase width to 110 mm. Servos remain unidentified, with editable assumed body/ear/shaft envelopes. The cuff is a cylindrical reference rather than a reconstructed thermoformed gauntlet or a fitted socket; the original wrist connection is not assembled in this reference view. No continuous tendon-motion, strap retention, fitted use, print strength, motor duty or electrical acceptance is claimed. Firmware is unchanged.

`cad/cuff_box/force_check.py` calculates required paired/thumb torque over explicit 5/10/15 N hand-tendon loads and 40/60/80% routing-efficiency scenarios. It also exposes a potentially large tipping load: the 10 N/60% simultaneous-pull example gives about 5.59 Nm around the nominal cuff crown when the exit cords run parallel to the forearm. That simplified load path is not a prediction of actual strap tension. Wrist stabilisation and a load-spreading attachment must be resolved on a bench before treating the module as wearable. The generic 25 kg·cm stall label and operating voltage remain unverified.

## Lower box and rigid arm adapter — finalised 9 October 2026

Seven print types (eight pieces) pass valid-single-solid and positive-volume watertight STL checks. The enclosure body is 94 × 96 × 54.9 mm, 23.2% lower than the preceding cuff box; removing strap ears reduces box width from 110 to 94 mm. This requires the shorter FT5425BL replacement-servo reference, not the unidentified owned motors.

The new open arm carrier connects to the box through four M4 positions and to the unchanged Phoenix hand through the palm receiver. Static component/cord, ear-envelope, adapter/receiver and reserved limb-volume checks pass. Thirteen sampled finger/thumb poses clear the new assembly. Six nominal mounting-screw shank/head allowances clear the exported print geometry. Source/output hashes and reimported assembly placements were checked; complete and open previews were inspected. See cad/cuff_box_compact/exports/checks.json and mount_checks.json.

A reproducible 10 N per hand-tendon, 60% efficiency scenario gives 0.410 Nm required paired-motor torque and a 3.74 Nm internal box pitch reaction around its seating plane. This is not net wearer torque: tendon reactions also enter the palm. No structural, suspension, pressure, actual motor/horn fit, complete cord routing or continuous-motion acceptance is claimed. Wrist axle retention, the palm restraint/stop pads and individual residual-limb fitting require physical work. Firmware is unchanged.
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

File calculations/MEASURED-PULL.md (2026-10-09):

# Check the actual tendon pull

**Historical equaliser layout.** For the current bottom-drive fixed paired grooves, use [BOTTOM-DRIVE-PULL.md](BOTTOM-DRIVE-PULL.md) and its measurement template/checker. Do not transfer the equaliser travel assumptions to the current kit.

Use this after assembling the hand on a bench fixture. Leave the servo disconnected. Measure at the point where its spool pulls the tendon, through the complete installed route and with the actual return bands. For the paired channels, retain the equaliser and both fingers during the measurement. Record peak pull and input travel, including the worst point in the movement.

Make a copy of `measured_pull_template.json`, enter readings for the thumb, index/middle pair and ring/little pair, and run:

```sh
python calculations/check_measured_pull.py my_measurements.json --output my_result.json
```

The supplied template contains **no measured forces or travels**. Its initial result is `MEASUREMENTS_REQUIRED`. Its radius, sweep, slack and torque are reference settings; replace them with justified values for the actual setup. `servo_and_sweep_confirmed` must remain false until the servo is identified, its torque allowance is justified at the lowest loaded supply voltage, and its usable endpoints are measured. The checker then reports `CALIBRATION_REQUIRED` if the arithmetic passes but this confirmation is missing. A `SCREEN_PASS` is only a torque/travel calculation, not hardware acceptance.

## Equations

With measured actuator-end force F in N, effective winding radius r in m, and separate load margin M:

- Required torque = M × F × r.
- Available travel = r × usable angle in radians.
- Minimum radius = (measured travel + slack allowance) / usable angle.
- Maximum radius = allowed torque / (M × measured force).

Use consistent units; the script accepts millimetres and converts internally. A feasible radius interval exists only when the minimum is no greater than the maximum. A small spool may have enough force but insufficient stroke; a large spool may provide the stroke but exceed the torque allowance.

**Do not apply a routing-efficiency factor again.** Measuring at the actuator end already includes losses along the route. The older finger-side estimates use an assumed efficiency because they do not have these measurements. Keep winding in one layer and account for the largest effective radius when checking torque.

The template's 0.6668522 N·m is the current candidate's 6 V rated-torque cap, converted from 6.8 kgf·cm. It comes from the [FT5425BL A/0 manufacturer specification, page 3](https://www.feetechrc.com/Data/feetechrc/upload/file/20210810/6376418710101296552903409.pdf). This does not identify the user's generic servos or establish continuous operation inside an enclosure. The 160° sweep and 3 mm slack reserve are starting assumptions.

The current equaliser has output holes 20 mm apart. At an assumed ±30° tilt, its ideal maximum output-travel difference is 20 sin(30°) = **10 mm**. This excludes line-angle effects and compliance. A pair requiring a greater difference can reach a bar stop even when mean travel is adequate. Measure the assembled pair and watch for this; a stopped bar does not continue equalising as assumed.

Record here before entering results:

| Channel | Peak actuator-end force (N) | Input travel (mm) | Sticking / early contact / bar stop |
| --- | --- | --- | --- |
| Thumb | not measured | not measured | |
| Index + middle | not measured | not measured | |
| Ring + little | not measured | not measured | |

Use a bench contact fixture to assess loaded closure. These calculations do not set safe tissue pressure or validate a fitted socket. Current, temperature, reopening, tendon wear, manual release and repeated operation remain separate checks.

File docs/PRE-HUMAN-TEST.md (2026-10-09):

# Before any human testing

**Status on 10 October 2026: HOLD.** The user reports an original Phoenix v3 hand print only. The bionic extension is not printed and the system is not wired. No physical test result, motor identification or wearer-specific fit has been supplied.

This is the working sequence for one intended wearer with a right missing hand. It separates work you can do now from decisions requiring an assembled fixture and a qualified prosthetic-fitting professional. The current arm adapter is a geometric candidate, not a prescribed socket.

## 1. What you can do now — no electronics needed

1. Inspect the original right-hand print against its source instructions. Record scale, material, print orientation, joint pins and any cracks or rough bearing surfaces.
2. Assemble the native hand joints, return bands and five tendon paths if not already assembled. Secure the palm on a rigid fixture. Check opening and closing manually without binding.
3. Measure each finger's force and travel using [the bottom-drive worksheet](../calculations/BOTTOM-DRIVE-PULL.md). Save repeated raw readings and photos. Label these hand-only results; they omit the extension's friction.
4. Identify the three servos using their case label and original order details. Measure body, mounting ears, shaft, horn and fastener stack. A “25 kg·cm” label does not establish voltage, dimensions or operating torque.
5. Compare those measurements with the selected FT5425BL candidate. The bottom-drive housing is not a verified fit for the owned generic servos. If they differ, revise the housing before printing.

Do not print the full extension merely to meet the current CAD dimensions. Start with measured motor/horn fit and representative mounting coupons. Hand-only force results can reject an unsuitable candidate early, but cannot establish the final motor margin.

## 2. Freeze the assembly and test criteria

The responsible engineer and fitting professional must agree intended tasks and limits before qualification: permitted loads/travel, speed, grip-release force/time, skin-contact temperature, power behaviour, duty cycle, structural proof/fatigue loads, cycle count and wear limits. Leave unknowns blank in the [test record](../release/production/bench_record_template.json); blank does not mean passed.

Complete the BOM with exact purchased parts and revisions: motors, metal horns, screws/retainers, tendon/liners/returns, regulator, power protection, disconnect, connectors, wire sizes, battery/BMS, band/backing and insulation. Record drawings, ratings, source evidence and measured sizes. Do not select a larger fuse to work around an unexplained trip.

Plan the complete load path through drum, motor ears, structural cover, case mounts, receiver, palm axle, stops, straps and socket. Specify print process and representative test articles. The original Phoenix wrist-powered gauntlet is not automatically suitable for a missing-hand conversion.

## 3. Mechanical fixture qualification

With the extension fitted to a rigid arm-shaped fixture and all power disconnected:

- Verify actual horn/fastener fit, engagement and retention. The paired drum's M2 hardware has only 0.6 mm nominal floor clearance under the stated head allowance. Measure it through full travel and under the agreed load; nominal CAD clearance is not acceptance.
- Check five complete tendon routes, terminations, one-layer winding, continuous motion, pinch points and reopening. Run the paired-travel screen on full-route readings.
- Restrain palm rotation with the actual stops and retention strap; the axle alone is a hinge.
- Verify the structural cover, printed motor posts, arm mounts and receiver with agreed load tests. Inspect deformation, cracks and fastener movement; retain measurements.
- Test simultaneous and asymmetric contact on objects/fixtures. Fixed two-groove pairs are not adaptive differentials.
- Resolve cable access and strain relief using [EMG mounting](EMG-MOUNTING.md). No body is needed to test plug fit, cover removal or snag clearance.

### Mechanical release is an unresolved design blocker

No validated release mechanism is currently included. Software disarm, signal detach and main power-off are insufficient because geared motors can resist opening. Before powered fitting, provide an externally accessible means to unload the five tendon paths without opening the motor cover, touching pinch points, requiring a motor to turn, or asking the wearer to pull against the grip.

A competent mechanical designer must choose and detail the release based on measured tendon loads and achievable access. Test it with power removed, a mechanically immobilised motor shaft and a downstream tendon jam on fixtures. Demonstrate actual finger opening and object release, not just movement of a lever. If a jam prevents opening, the mechanism fails that case. Verify retention during normal use and access in the prescribed fitted position. No release-time or load rating is claimed here.

Do not improvise a live jam with hands in the mechanism, or cut a loaded tendon near a person as the planned emergency procedure.

## 4. Electrical commissioning — all electrodes off people

Use the updated [wiring specification](WIRING.md), labelled harness and recorded component ratings. Keep motor plugs disconnected initially.

1. Inspect continuity, polarity, insulation and absence of shorts. Verify regulated outputs on dummy loads before connecting boards.
2. Check the output-disabled firmware and sensor signal path using an appropriate test source. Measure the regulator under its real load.
3. Only on the fixture, set SERVO_OUTPUTS_ENABLED true for unloaded motor commissioning. Start with horns/tendons removed. Confirm each motor direction and safe endpoints; inversion changes the required winding direction.
4. Confirm startup/restart with S2 held cannot enable pulses. Release S2 for at least 50 ms after calibration, then hold it and allow a relaxed input before commanding closure. Check disarm, timing fault, ADC fault and timeout.
5. Attach loose tendons and increase the agreed command range gradually. Measure voltage/current at the actual motor and logic connectors, including simultaneous motion. Check overshoot, sag, return-current interference, inrush, connector and enclosure temperatures.
6. Exercise input disconnects, frozen input, plausible noise, brownout, restart and control loss under a defined fixture fault plan. Record actual behaviour. The ADC check does not reliably identify lost skin contact; the software has no force, current or temperature feedback.
7. Demonstrate both electrical disconnect and independent mechanical release. Retest affected cases after any revision.

The software's nominal 1 kHz sample rate must be measured on the board. Do not infer timing, servo response or force from a successful compile. Routine host tests model logic only.

## 5. Repeatability and durability

Run the pre-agreed load and duty sequence with representative objects and all five routes installed. Record cycle count, currents, temperatures, force/travel changes, failures, screw movement and wear. Include release tests before and after the run. Replace worn components and document any design change; rerun affected checks on the final configuration.

An arbitrary “100 cycles passed” is not a life or clinical claim. Acceptance criteria and intended service interval must be justified before the test.
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

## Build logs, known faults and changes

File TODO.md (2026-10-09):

## Current next steps — 10 October 2026

Use [the staged pre-human-test procedure](docs/PRE-HUMAN-TEST.md). Current hardware is the original Phoenix v3 print only. First record unpowered hand force/travel and identify the owned servos, then resolve extension fit and mechanical release before powered fitting. The new wiring, mounting notes, output-disabled firmware and calculation checker are preparation, not passed physical tests.

## Bottom-drive verification

- [ ] Measure full-route tendon forces before and after rerouting; do not infer a pull-force gain from inversion alone.
- [ ] Verify motor-ear bolt/nut lengths, cover attachment and hanging-motor retention on a bench.
- [ ] Recalibrate winding direction and endpoints with cords disconnected.
- [ ] Check service lead slack, cord anchors, full moving wraps, manual release and enclosed motor temperature.

## Lower box and rigid adapter follow-up

- [ ] Measure replacement servo/horn/connector fit before printing.
- [ ] Fit and test wrist axle, palm strap and broad stop pads on a bench.
- [ ] Verify mounting fasteners, print strength and strap retention under measured tendon loads.
- [ ] Establish individual residual-limb fit, liner, suspension and electrode contact before powered wear.

# Remaining work

## Separate cuff-box option

- [x] Design a new strap-on enclosure with servo seats, upright electronics carrier, two paired drums and one thumb drum, preserving source hand/cuff geometry.
- [ ] Measure the owned motors, metal horns, connectors and switch bodies; regenerate this option for those measurements.
- [ ] Fit the saddle padding and straps to the actual formed cuff; resolve wrist stabilisation before loading direct tendons.
- [ ] Measure each paired cord's force/travel, check unequal-contact behaviour and accessible release, and validate the external power system.

## Current forearm design — 8 October 2026

- [x] Add original-proportion hand scaling, independent arm clearance controls and explicit anthropometric landmark checks in `cad/sizing`.
- [x] Generate a 120% example receiver with fixed forearm bolt centres and local lower-shell head clearances; export and check the matching assembly.
- [ ] Select a hand scale through virtual fitting, verify matching printed pins/axle and chosen fasteners, and rerun interface/motion/travel checks for that selection.
- [ ] Assess socket trim lines, elbow movement, suspension, electrode site, one-handed release and measured device balance with the intended wearer.

- [x] Confirm finger order against the original v3 placemat; restore the native thumb hinge, remove the extra fork, and clear eight sampled thumb poses.
- [x] Replace the external box with split curved forearm shells, an internal servo shelf, battery cradle and removable electronics tray.
- [x] Put the two equaliser lanes and separate thumb lane inside the arm; recess the controls.
- [x] Preserve empty placeholder limb space and provide an electrode window and side cable passage.
- [x] Export seven checked new STEP/STL parts and exterior/internal CAD previews.
- [ ] Measure available residual-end-to-wrist distance; replace the 160 mm equipment-space assumption and fit socket/liner/suspension to the recipient.
- [x] Match complete/open/detail exports and check thirteen simultaneous closure poses.
- [x] Align spool centres with the candidate servo drawing and add a measured-pull checker.
- [x] Roll all five inverted distal parts into the correct orientation; verify sampled finger bends through 60°.
- [ ] Verify actual pins, physical extension stops, return bands and continuous full closure. The 10° resting PIP bend is a CAD setting; the 45° MCP / 15° PIP pose remains a limited illustration.
- [ ] Select and measure the FT5425BL variant, protected 2S battery, high-current disconnect/protection, connectors and low Nano connections; replace reference envelopes.
- [ ] Fit and verify all bolts/nuts/axles, battery/servo/palm restraints, seam-boss strength and service access. Do not assume CAD bores are usable threads.
- [ ] Install flexible tendons/liners around the motors; check crossing, bend radii and manual release, then measure complete-path tension and required travel.
- [ ] Perform current, noise, thermal, wear, reopening, repeated-cycle and mechanical load tests before any fitted use.

The sections below preserve earlier work and outstanding baseline tests. [The forearm guide](cad/forearm/README.md) controls current file selection; old box previews and part lists are historical.

## Files completed
- [x] Select classic Nano and SEN0240; set three groups: thumb, index/middle, ring/little.
- [x] Write simple EMG control firmware and retain OYMotion notices.
- [x] Compile for Nano and test control logic on the host.
- [x] Draw proposed wiring and list power/protection components.
- [x] Import official Phoenix STEP; preserve original geometry.
- [x] Create editable carrier, spool, fairlead and equaliser CAD; export STEP/STL.
- [x] Create the reference BOM with quantities and explicit cost allowances.

- [x] Add an integrated electronics/battery enclosure, lid, switches and strap station; export checked reference geometry.

## Before connecting loaded tendons
- [ ] Select exact battery, switches, fuse holder and connector sizes; update assumed CAD envelopes.
- [ ] Check board headers, USB alignment, switch threads and wire service loops against the physical components.
- [ ] Identify actual servo voltage range, spline, body dimensions and connector pinout.
- [ ] Print a test fit; check horn bolts, cable exits, ties and clearances.
- [ ] Measure tendon force and travel using [TENDON-TEST.md](TENDON-TEST.md).
- [ ] Rerun torque sizing for the actual line radius and equaliser routing.
- [ ] Check supply voltage, polarity, fuse/wire ratings and regulator temperature.
- [ ] Calibrate pulse endpoints with horns/tendons disconnected, then loose tendons.

## Hardware validation
- [ ] Verify sampling timing, relaxed/contraction separation and motor-noise immunity.
- [ ] Test reopening, arming, timeout and faults; establish manual tendon release.
- [ ] Check paired-finger contact, equaliser travel and line wear.
- [ ] Measure current, heating and performance over repeated cycles and intended holding duration.
- [ ] Choose hand scale and design a proper cuff; validate retention and cooling in the new enclosure.
- [ ] Record cost quotations, final assembly photos, test data and demonstration video.
- [ ] Review historical project claims separately from results of this reconstruction.

## Superseded custom-hand study (revision C)
- [x] Generate new palm, two-joint fingers, opposed thumb, wrist plate and compact housing CAD.
- [x] Check printable solids, component clashes and sampled finger/thumb motion.
- [ ] Confirm left/right hand, amputation level, residual-limb dimensions and socket/interface requirements with the intended user and prosthetist.
- [ ] Complete constrained tendon routing, equaliser mounts and service access.
- [ ] Establish joint stops, return-elastic preload, friction and required tendon travel on one finger.
- [ ] Verify real servo ears, horns, battery, switches and cable bends in the compact enclosure.
- [ ] Validate wrist fasteners, housing cooling and load retention on a bench before fitting.

## Current Phoenix v3 adaptation
- [x] Add right-arm open saddle and independent EMG-band carrier using the published electrode board outline.
- [ ] Replace placeholder lumen with assessed right residual-limb/socket geometry; resolve anatomical length, suspension, liner and skin-pressure requirements.
- [ ] Measure electrode package thickness/contact protrusion and verify its independent soft retention and cable route.
- [x] Remove the unused spool groove and lower maximum enclosure height to 60 mm; calculate force/travel at the retained radius.
- [ ] Verify thinner-spool horn bolts, tendon anchors and 2.75 mm nominal roof clearance; measure force/travel through the complete routing.
- [x] Round the housing corners, lower the rear roof and recess the controls/cover screws.
- [ ] Slice the curved lid with suitable supports; test thin screw seats, actual low-profile heads and both fastener lengths.
- [x] Restore original Phoenix v3 palm, finger and pin geometry as the selected hand.
- [x] Export original source parts and add a wrist-pivot cradle study for the compact housing.
- [ ] Right side confirmed; confirm Phoenix scale and residual-limb requirements and socket/interface dimensions.
- [ ] Verify the original thumb orientation against the official assembly guide; remove the exploded-view offset only after confirming fit.
- [ ] Select and verify wrist axle/retention, and complete a neutral-position wrist lock.
- [ ] Complete servo-to-Phoenix tendon routing and restrained paired-finger equalisers.
- [ ] Verify original joints, tendon forces/travel, motor limits, enclosure fit and loaded assembly on a bench.

## Integrated bionic CAD — prototype 0.2
- [x] Read current personal-statement v4 and retain its architecture.
- [x] Add closed distal shell, removable ventral door and electrode access.
- [x] Add a palm receiver and connected thumb fork; retain source palm/finger shapes.
- [x] Add constrained equaliser cassette, thumb-line slider, real guide ports and wrist liner comb.
- [x] Add dedicated housing liner entries and reinforced cassette-bearing seats.
- [x] Expose the simple 32-sample averaging helper; compile Nano firmware and rerun host control/filter tests.
- [ ] Choose actual thumb shoulder axle, wrist axle/retainers, clamp supports, inserts and fastener lengths; physically verify joint play and retention.
- [ ] Install and measure flexible-line paths, slack, bends, equaliser differential travel and accessible manual release.
- [ ] Test original finger articulation and the new thumb mount throughout the required motion on a bench.
- [ ] Fit the socket/suspension/liner to measured right residual-limb anatomy and verify EMG contact and skin pressure.
- [ ] Measure actual closure/contact forces, noise, heating, grip and repeated-cycle behaviour.

The earlier exploded-thumb and open-saddle entries are historical design stages. The 0.2 CAD now supplies a connected mount and full shell; physical acceptance remains open.

## Small exterior refinement — 6 October 2026

- [x] Round cassette walls and thumb-support corners without changing mounting centres or overall part envelopes.
- [x] Soften the cassette cover edge and add shallow screw-head seats.
- [x] Recheck meshes, static assembly clearances, equaliser travel and sampled thumb positions.
- [ ] Measure selected cover screw heads and verify the 2 mm remaining seat and insert engagement on a printed sample.

## Smaller-part candidate — 6 October 2026

- [x] Compare low-profile servo size, travel and voltage-dependent torque using manufacturer specifications.
- [x] Model a 50 mm-high pack with FT5425BL reference bodies and low Nano connections.
- [ ] Confirm servo ears, shaft/horn dimensions, screw engagement and actual Nano/USB clearance.
- [ ] Select a measured protected 2S pack and coordinated disconnect/fuse/wire/connector system for the new current demand.
- [ ] Measure tendon force and voltage sag at the lowest intended battery voltage; verify thermal duty.

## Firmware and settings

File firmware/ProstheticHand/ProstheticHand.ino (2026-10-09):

// SPDX-License-Identifier: MIT
// Nano + DFRobot SEN0240. OYMotion filter files retain their BSD-2-Clause licence.
#include <Servo.h>
#include "EMGFilters.h"
#include "HandControl.h"

const byte EMG_PIN = A0;
const byte ARM_PIN = 2;             // Normally-open hold-to-enable switch to GND.
const byte SERVO_PINS[] = {9, 10, 11}; // Thumb, index+middle, ring+little.
// Small initial test movement, NOT calibrated full-hand endpoints.
// First test with horns/tendons disconnected. Adjust each pair for your linkage.
const int OPEN_US[]  = {1100, 1100, 1100};
const int CLOSE_US[] = {1300, 1300, 1300};
const int STEP_US = 10;             // Every 20 ms; limits commanded closing rate.
const bool PLOT = false;            // Diagnostic serial output, 20 Hz.
// Shipping configuration: signal processing only, NO servo pulses.
// Set true only for supervised fixture commissioning with horns/tendons removed.
// This setting is not permission for human use. See docs/PRE-HUMAN-TEST.md.
const bool SERVO_OUTPUTS_ENABLED = false;

Servo servos[3];
EMGFilters filter;
HandControl hand;
int positionUs[3];
uint32_t nextSample, lastServo = 0, lastPlot = 0;

void setup() {
  pinMode(ARM_PIN, INPUT_PULLUP);
  pinMode(LED_BUILTIN, OUTPUT);
  Serial.begin(115200);
  filter.init(SAMPLE_FREQ_1000HZ, NOTCH_FREQ_50HZ, true, true, true);
  // Match DFRobot's 1 kHz filtering and squared activity, then average it.
  nextSample = micros();
  for (byte i = 0; i < 3; ++i) positionUs[i] = OPEN_US[i];
  // Servos remain detached during the five-second relaxed calibration.
}

void loop() {
  uint32_t now = micros();
  if ((int32_t)(now - nextSample) < 0) return;
  if (now - nextSample >= 2000) {
    hand.fault = true;              // Timing was lost: reset and recalibrate.
    nextSample = now;
  }
  nextSample += 1000;
  int raw = analogRead(EMG_PIN);
  hand.sample(filter.update(raw), raw, digitalRead(ARM_PIN) == LOW);

  bool enabled = SERVO_OUTPUTS_ENABLED && hand.enabled;
  // Detach on the next sample, rather than waiting for a 20 ms servo update.
  // Firmware can hang; this is NOT a hardwired disconnect or a grip release.
  if (!enabled) {
    for (byte i = 0; i < 3; ++i) {
      servos[i].detach();
      positionUs[i] = OPEN_US[i];
    }
  }

  uint32_t ms = millis();
  if (ms - lastServo >= 20) {
    lastServo = ms;
    for (byte i = 0; i < 3; ++i) {
      if (!enabled) {
        continue;
      }
      if (!servos[i].attached()) {
        servos[i].writeMicroseconds(OPEN_US[i]);
        servos[i].attach(SERVO_PINS[i], 500, 2500); // FT5425BL reference only; verify actual unit.
      }
      int target = hand.closed ? CLOSE_US[i] : OPEN_US[i];
      if (positionUs[i] < target) positionUs[i] = min(positionUs[i] + STEP_US, target);
      if (positionUs[i] > target) positionUs[i] = max(positionUs[i] - STEP_US, target);
      servos[i].writeMicroseconds(positionUs[i]);
    }
    digitalWrite(LED_BUILTIN, hand.fault ? (ms / 150) % 2 : hand.calibrated);
  }
  if (PLOT && ms - lastPlot >= 50 && Serial.availableForWrite() >= 40) {
    lastPlot = ms;
    Serial.print(hand.level); Serial.print(' ');
    Serial.print(hand.threshold); Serial.print(' ');
    Serial.println(hand.closed ? hand.threshold : 0);
  }
}

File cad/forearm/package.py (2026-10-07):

"""Package the current forearm candidate with explicit selection and SHA-256 hashes."""
from pathlib import Path
import hashlib, json, subprocess, zipfile
R = Path(__file__).resolve().parents[2]
cad = R / 'cad/forearm'
check = json.loads((cad / 'checks.json').read_text())
layout = json.loads((cad / 'layout_checks.json').read_text())
assert all(max(p['overlap_mm3'].values()) < .001 for p in layout['sampled_thumb_poses'])
motion = json.loads((cad / 'motion_checks.json').read_text())
assert not check['collisions'] and not check['lumen_intrusions']
assert all(p['watertight'] for p in check['parts'].values())
assert not motion['partial_finger_collisions']
assert max(motion['shell_lumen_overlap_mm3'].values()) < .001
assert all(max(p['overlap_mm3'].values()) < .001 for p in motion['mechanism_poses'])
assert motion['full_flexion_accepted'] is False
finger_checks = json.loads((cad / 'exports/finger_motion_diagnostic.json').read_text())
assert max(max(p['overlap_mm3']) for p in finger_checks) < .001
axes = json.loads((cad/'servo_axis_checks.json').read_text())
assert all(row['axis_error_mm']<1e-4 for row in axes['rows']) and len(axes['rows'])==3
assert axes['assembly_sha256']==hashlib.sha256((cad/'exports/complete_forearm.step').read_bytes()).hexdigest()
closure = json.loads((cad / 'closure_checks.json').read_text())
assert closure['all_samples_clear'] and len(closure['samples'])==13
assembly = json.loads((cad / 'assembly_checks.json').read_text())
for n,item in assembly['assemblies'].items():
 assert hashlib.sha256((cad/'exports'/(n+'.step')).read_bytes()).hexdigest()==item['sha256'],n
for n,digest in assembly['source_sha256'].items():
 assert hashlib.sha256((cad/n).read_bytes()).hexdigest()==digest,n
for n,digest in assembly['preview_sha256'].items():
 assert hashlib.sha256((cad/'exports'/n).read_bytes()).hexdigest()==digest,n
selected = {f'cad/forearm/exports/{n}.stl': 1 for n in check['parts']}
selected.update({
    'cad/forearm/exports/complete_forearm.step': None,
    'cad/compact/exports/single_groove_spool.stl': 3,
    'cad/exports/pair_equaliser.stl': 2,
    'cad/arm_interface/exports/emg_band_carrier.stl': 1,
})
manifest = {
    'version': '0.4.3-forearm', 'entrypoint': 'cad/forearm/README.md',
    'status': 'Unfitted design candidate; continuous loaded closure and power parts unresolved',
    'selected_files': {p: {'quantity': q, 'sha256': hashlib.sha256((R / p).read_bytes()).hexdigest()}
                       for p, q in selected.items()},
    'validation_files': {str(p.relative_to(R)): hashlib.sha256(p.read_bytes()).hexdigest()
                         for p in [cad/'checks.json', cad/'motion_checks.json',
                                   cad/'exports/finger_motion_diagnostic.json', cad/'layout_checks.json', cad/'source_review.json', cad/'assembly_checks.json', cad/'closure_checks.json', cad/'servo_axis_checks.json']},
}
(cad / 'manifest.json').write_text(json.dumps(manifest, indent=2) + '\n')
paths = set(filter(None, subprocess.check_output(['git', 'ls-files', '-z'], cwd=R).decode().split('\0')))
paths.add('cad/forearm/manifest.json')
assert set(selected).issubset(paths), 'Stage new files before packaging.'
target = Path('/tmp/Bionic-Prosthetic-hand-0.4.3-forearm.zip')
with zipfile.ZipFile(target, 'w', zipfile.ZIP_DEFLATED) as z:
    for p in sorted(paths):
        if (R / p).is_file(): z.write(R / p, 'Bionic-Prosthetic-hand/' + p)
with zipfile.ZipFile(target) as z:
    assert z.testzip() is None
print(f'{len(paths)} files; verified {target}')

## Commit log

2026-09-26 Describe EMG processing, tendon actuation and compact mechanical coupling
2026-09-26 Add SERVO-SIZING.md with provisional assumptions and verification requirements
2026-09-26 Add BOM.md with provisional assumptions and verification requirements
2026-09-26 Add practical tendon force and travel measurement procedure
2026-09-26 Specify selected electronics and distinguish reference servo data from measurements
2026-09-26 Add Nano EMG firmware, three-servo CAD, wiring and reference BOM
    [carrier_assembly.step, pair_equaliser.step, pair_equaliser.stl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]
2026-09-26 Mark generated CAD and upstream filter sources for review
2026-09-26 Add integrated electronics enclosure and component fit coupons
    [electronics_lid.step, electronics_lid.stl, integrated_assembly.step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]
2026-09-27 Add experimental minimal hand and compact three-servo housing
    [compact_assembly.step, compact_base.step, compact_base.stl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]
2026-09-27 Improve CAD preview surface shading
    [complete_reference_assembly.step]
2026-09-27 Base current motorised hand on original e-NABLE Phoenix v3 geometry
    [distal_long_a.step, distal_long_b.step, distal_short_a.step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]
2026-10-05 Round Phoenix motor housing and lower rear roof
    [compact_assembly.step, compact_base.step, compact_base.stl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]
2026-10-05 Lower housing with single-groove spools and calculate tendon forces
    [compact_assembly.step, compact_base.step, compact_base.stl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]
2026-10-05 Add right forearm saddle and independently strapped EMG carrier
    [emg_band_carrier.step, emg_band_carrier.stl, right_open_saddle.step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]
2026-10-05 Package prototype 0.1 with definitive build guide and file manifest
2026-10-05 Integrate right bionic hand, socket and guided tendon drive
    [fixed_palm_receiver.step, fixed_palm_receiver.stl, housing_lid_with_feedthroughs.step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]
2026-10-06 Soften bionic cassette and support profiles without moving interfaces
    [fixed_palm_receiver.step, fixed_palm_receiver.stl, tendon_cassette_base.step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]
2026-10-06 Add slimmer replacement-servo CAD with force and power assessment
    [compact_assembly.step, compact_base.step, compact_base.stl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]
2026-10-06 Integrate components into forearm and correct Phoenix placement
    [corrected_fingers.step, electronics_tray.step, electronics_tray.stl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]
2026-10-07 Restore Phoenix v3 native thumb joint and verify original layout
    [hand_layout.step, palm_receiver.step, palm_receiver.stl]
2026-10-07 Flip Phoenix distal parts into correct dorsal orientation
    [corrected_fingers.step, hand_layout.step, partial_flexion_fingers.step]
2026-10-07 Verify complete hand exports and align servo spools to source drawing
    [corrected_fingers.step, hand_layout.step, servo_axis_checks.json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]
2026-10-07 Add adjustable Phoenix hand sizing and anthropometric clearance study
    [limb_clearance_envelope.step, scaled_hand.step]
2026-10-08 Build adjustable wrist receiver with matching forearm head clearances
    [forearm_lower_head_clearance.step, forearm_lower_head_clearance.stl, resized_receiver.step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]
2026-10-08 Add separate Phoenix cuff-mounted servo box and load worksheet
    [box_base.step, box_base.stl, box_lid.step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]
2026-10-09 Lower paired-finger servo box and add rigid open arm adapter
    [arm_adapter.step, arm_adapter.stl, box_base.step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]
2026-10-09 Invert servo cartridge for lower tendon exits with bolted motor mounts
    [arm_adapter.step, arm_adapter.stl, box_base.step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]
2026-10-09 Prepare bench verification and inhibit uncommissioned servo outputs

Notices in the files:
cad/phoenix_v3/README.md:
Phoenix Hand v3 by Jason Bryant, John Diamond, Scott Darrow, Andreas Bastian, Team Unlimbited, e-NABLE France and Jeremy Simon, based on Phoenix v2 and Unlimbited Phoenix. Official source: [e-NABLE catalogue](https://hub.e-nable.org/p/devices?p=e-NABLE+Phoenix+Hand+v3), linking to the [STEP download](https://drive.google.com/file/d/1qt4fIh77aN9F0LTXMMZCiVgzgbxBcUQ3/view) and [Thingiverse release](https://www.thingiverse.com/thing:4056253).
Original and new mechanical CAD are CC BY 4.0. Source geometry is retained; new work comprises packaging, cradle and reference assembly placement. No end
